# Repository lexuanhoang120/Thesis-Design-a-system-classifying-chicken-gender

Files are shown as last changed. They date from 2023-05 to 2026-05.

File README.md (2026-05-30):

# Chicken Gender Classification System

> **Undergraduate Thesis** — HCMC University of Technology (Bách Khoa), Mechatronics, 2022

A CNN-powered system that automatically sorts chickens by gender. Built from scratch: collected the dataset on a farm, trained the classifier, designed the mechanical singulation mechanism, wired the control electronics, and ran live experiments with real chickens.

---

## Highlights

- **95.9% classification accuracy** using a custom CNN with multi-frame majority voting — up from 91.5% single-frame
- **Self-collected dataset** — photographed hundreds of chickens one-by-one on a local farm, published on Kaggle
- **Full mechatronic system** — mechanical design (CAD), electrical wiring, embedded control (ATMega 2560), and computer vision — all integrated into a working prototype
- **~0.22s single-frame inference** for real-time use; **4.56s** with 20-frame voting for near-96% accuracy
- **4.4 pp accuracy gain** from a simple ensemble strategy that costs nothing but a few extra frames

---

## Results

**Experiment 1 — Single frame (200 chickens):**

| | Actual Cock | Actual Hen |
|---|---|---|
| **Predicted Cock** | **92** | 9 |
| **Predicted Hen** | 8 | **91** |

→ **91.5% accuracy**, ~0.22s per prediction

**Experiment 2 — Multi-frame voting (171 chickens):**

Take 20 frames, predict each independently, majority vote. Sum > 10 → hen, < 10 → cock.

| | Actual Cock | Actual Hen |
|---|---|---|
| **Predicted Cock** | **84** | 4 |
| **Predicted Hen** | 3 | **80** |

→ **95.9% accuracy** (+4.4 pp), ~4.56s per prediction  
→ Cock: 96.55%, Hen: 95.24%

The voting strategy trades speed for accuracy — worth it because the mechanical singulation is the bottleneck, not the classifier.

---

## How it works

```
Flock → Singulation mechanism → One chicken in the cage
                                       ↓
                              Camera captures image(s)
                                       ↓
                              CNN classifier → Cock or Hen
                                       ↓
                              Sorting gate → Correct bin
```

**Three integrated subsystems:**

| Subsystem | What it does | Key components |
|---|---|---|
| **Computer Vision** | Classifies gender from images | Custom CNN (4 conv + 2 dense), 256×256 RGB input |
| **Mechanical** | Isolates one chicken at a time | Gates, pusher plate, timing belt, stepper motor, servo |
| **Electrical & Control** | Orchestrates the sequence | ATMega 2560, IR sensors, motor drivers, 12V supply |

---

## The CNN classifier

### Data

Collected in person at a local chicken farm. Each bird was placed in a fixed cage under controlled LED lighting and photographed with a smartphone. The dataset was split into train/validation/test with augmentation.

<!-- 📦 [Kaggle Dataset](https://www.kaggle.com/datasets/hongxun/dataset-chicken-gender) · [Raw Data](https://www.kaggle.com/datasets/hongxun/raw-data-chicken-gender) · [Trained Model](https://www.kaggle.com/datasets/hongxun/classify-chicken-gender) · [All Materials](https://www.kaggle.com/datasets/hongxun/material-classify-chicken-gender) -->

### Architecture

| Layer | Details |
|---|---|
| Input | 256×256 RGB |
| Conv Block 1–4 | Increasing filters, ReLU, MaxPooling, Dropout |
| Dense | 2 fully-connected layers |
| Output | Sigmoid → binary (0 = Cock, 1 = Hen) |

Tested multiple architectures iteratively — selected the best balance of accuracy and inference speed.

### Key lessons

- **Environmental consistency matters.** Training images looked slightly different from on-site captures, which caused the real-world accuracy drop from training performance. Re-collecting data to match deployment conditions was the fix.
- **Chicken movement degrades single-frame accuracy.** A 20-frame voting strategy was a zero-cost fix — no model retraining, just capturing more frames and taking the majority.
- **Data collection is the hardest part.** Every sample means catching a chicken, placing it correctly, and labeling it. No shortcut for this.

---

## Demos & drawings

**Experiments:**

1. Building the model + initial testing — https://youtu.be/ve8OjjkXJxA
2. Results from experiment 1 — https://youtu.be/6x_dHk-QXaI
3. Results from experiment 2 + chicken measurements — https://youtu.be/hFi8iOCUlrs

**System animation:** https://youtu.be/mFdrJw7o6yE

**Design drawings:** [Algorithm](Drawing/algorithm.pdf) · [Mechanical](Drawing/mechanic.pdf) · [Electrical](Drawing/electric.pdf) · [Component selection](Drawing/selections.pdf)

---

## Project structure

```
.
├── VP ... HĐ11.pdf               # Full thesis (Vietnamese)
├── Drawing/                      # CAD drawings (DWG + PDF)
│   ├── algorithm.{dwg,pdf}
│   ├── mechanic.{dwg,pdf}
│   ├── electric.{dwg,pdf}
│   └── selections.{dwg,pdf}
├── #Kinematic diagram/           # Kinematic mechanism diagrams (Visio)
├── clip/                         # Experiment YouTube links
└── README.md
```

---

## Additional figures

### Classification problem

Classification problem

### Implementation planning

Implementation planning

### Build data

Build data

### Model structure

Model structure

Model structure 2

### Evaluation

Evaluation

### Experiment

Experiment

### Result

Result

### Improvement

Improvement

### Mechanical model

Mechanical model

Mechanical model 2

### Electrical model

Electrical model

Electrical model 2

### Summary

Summary

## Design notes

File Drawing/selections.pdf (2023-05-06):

## HỆ THỐNG PHÂN LOẠI GÀ

- Tách gà trong lồng thành từng con.
- Phân loại giới tính gà.

## PHẦN ĐIỆN

Động cơ

MỤC TIÊU

## PHẦN CƠ KHÍ

Cơ cấu tách gà

## Chọn động cơ RC Servo để phụ trách

hoạt động cho cụm đóng mở cửa lồng.

Cơ cấu đóng mở cửa

Thuỷ lực khí nén

RC Servo

- Khá phức
tạp. - Yêu cầu

thiết bị tạo
lưu chất. - Chi phí cao. - Hành trình

đáp ứng
chậm. - Cần khả năng

tạo xung
PWM của bộ
điều khiển
để điều
khiển động
cơ.

Bộ điều khiển

## Chọn kit Vi điều khiển làm bộ điều

khiển cho mô hình tách gà.

Programmable Logic
Controller (PLC)

Kit vi điều khiển

- Lập trình
đơn giản, dễ
sử dụng. - Được thiết

kế để sử
dụng trong
môi trường

# công nghiệp. - Giá thành rẻ. - Nhiều đầu

vào và đầu
ra.
- Giá thành
cao. - Không tận

dụng hết khả
năng của

# PLC. - Lập trình

phức tạp. - Cần thêm

thành phần
bảo vệ.

## PHẦN GIẢI THUẬT

## Chọn mô hình máy học CNN để đào tạo

phân loại giới tính gà.

Mô hình phân loại gà

Convolutional Neural Network (CNN)

Support Vector Machine
(SVM)
- Cho kết quả
chính xác
hơn.
- Sử dụng
trực tiếp ảnh
đầu vào để
đào tạo. | - Kiến trúc mô hình phức tạp hơn. - Thời gian
| dự đoán
lâu hơn. - Tốc độ suy

luận nhanh
hơn. - Kiến trúc mô

hình đơn

giản hơn. | - Kết quả chính xác không cao. - Bắt buộc
| phải chuyển dữ liệu thành vector.
Phương án | Ưu điểm | Nhược điểm

3 khối trụ xoay dọc

Lùa gà qua cửa hẹp

Sử dụng cụm băng tải

- Cơ cấu tách
gà thành
từng con
một. - Tầm hoạt
động rộng. | - Gia công chế tạo phức tạp. - Khả năng
| làm tổn thương

đối tượng. - Giá thành rẻ,

dễ gia công. - Số lượng gà

đi vào hệ
thống nhiều. - Tầm hoạt

động rộng.

- Cần cải
tiến để có
thể tách
gà. - Khả năng

làm tổn
thương đối
tượng cao. - Dễ gia công,

chế tạo. - Không làm

tổn thương

đối tượng. | - Tầm hoạt động hẹp. - Khó khăn
| trong việc đồng bộ hệ thống.

## Chọn phương án lùa gà qua khe hẹp

làm phương án tách gà.

- Hành trình
đáp ứng
nhanh. - Điều khiển

đơn giản.

Động cơ Servo

Động cơ thường

Động cơ bước

- Giá thành
cao. - Điều khiển

phức tạp. - Điều khiển

đơn giản. - Giá thành rẻ. - Phổ tốc độ

rộng. | - Bảo trì, bảo dưỡng thường xuyên. - Cần tích hợp

phanh. - Giá thành

cạnh tranh. - Có khả năng

giữ trục

động cơ. | - Khả năng trượt bước. - Ồn ào và
| sinh nhiệt cao.

## Chọn động cơ bước để dẫn động các

cụm trong mô hình tách gà.

YÊU CẦU

- Có khả năng tách gà thành từng con. - Ý tưởng đơn giản, dễ thiết kế.

YÊU CẦU

- Hoạt động ở hai trạng thái đóng và mở cửa. - Đơn giản và tiết kiệm.

YÊU CẦU

- Gọn nhẹ nhất có thể. - Có khả năng giữ trục khi không hoạt động. - Hoạt động êm ái.

YÊU CẦU

- Có khả năng nhận tín hiệu và xử lý để gửi tín hiệu tới các thành phần để điều khiển các cơ cấu thừa hành.

YÊU CẦU

- Khả năng nhận biết gà trống và gà mái.
- Đơn giản, dễ
sử dụng. - Giá thành rẻ.
- Có khả năng
giữ trục khi
không hoạt
động. - Hoạt động

êm ái.

Phương án | Ưu điểm | Nhược điểm | Phương án | Ưu điểm | Nhược điểm | Phương án | Ưu điểm | Nhược điểm | Phương án | Ưu điểm | Nhược điểm

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
1 | 2
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
1 | 2 | 3 | 4 | 5 | 6 | 7 | 8 | 9 | 10 | 11 | 12 | 13 | 14 | 15 | 16 | 17 | 18 | 19 | 20 | 21 | 22 | 23 | 24
3 | 4 | 5 | 6 | 7 | 8 | 9 | 10 | 11 | 12 | 13 | 14 | 15 | 16 | 17 | 18 | 19 | 20 | 21 | 22 | 23 | 24
Tờ: 1 | Số tờ: 4
Hướng dẫn | P. C. Bằng

Duyệt

PHÂN TÍCH VÀ THIẾT KẾ HỆ THỐNG PHÂN LOẠI GÀ

Chức năng | Họ và tên | Chữ kí | Ngày | LỰA CHỌN PHƯƠNG ÁN | Dấu | Khối lượng | Tỉ lệ
Thiết kế | L. X. Hoằng | | 21/05

Đại học Quốc gia TP.HCM
Trường Đại học Bách Khoa
Khoa Cơ khí
P. C. Bằng

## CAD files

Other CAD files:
Drawing/algorithm.dwg
Drawing/electric.dwg

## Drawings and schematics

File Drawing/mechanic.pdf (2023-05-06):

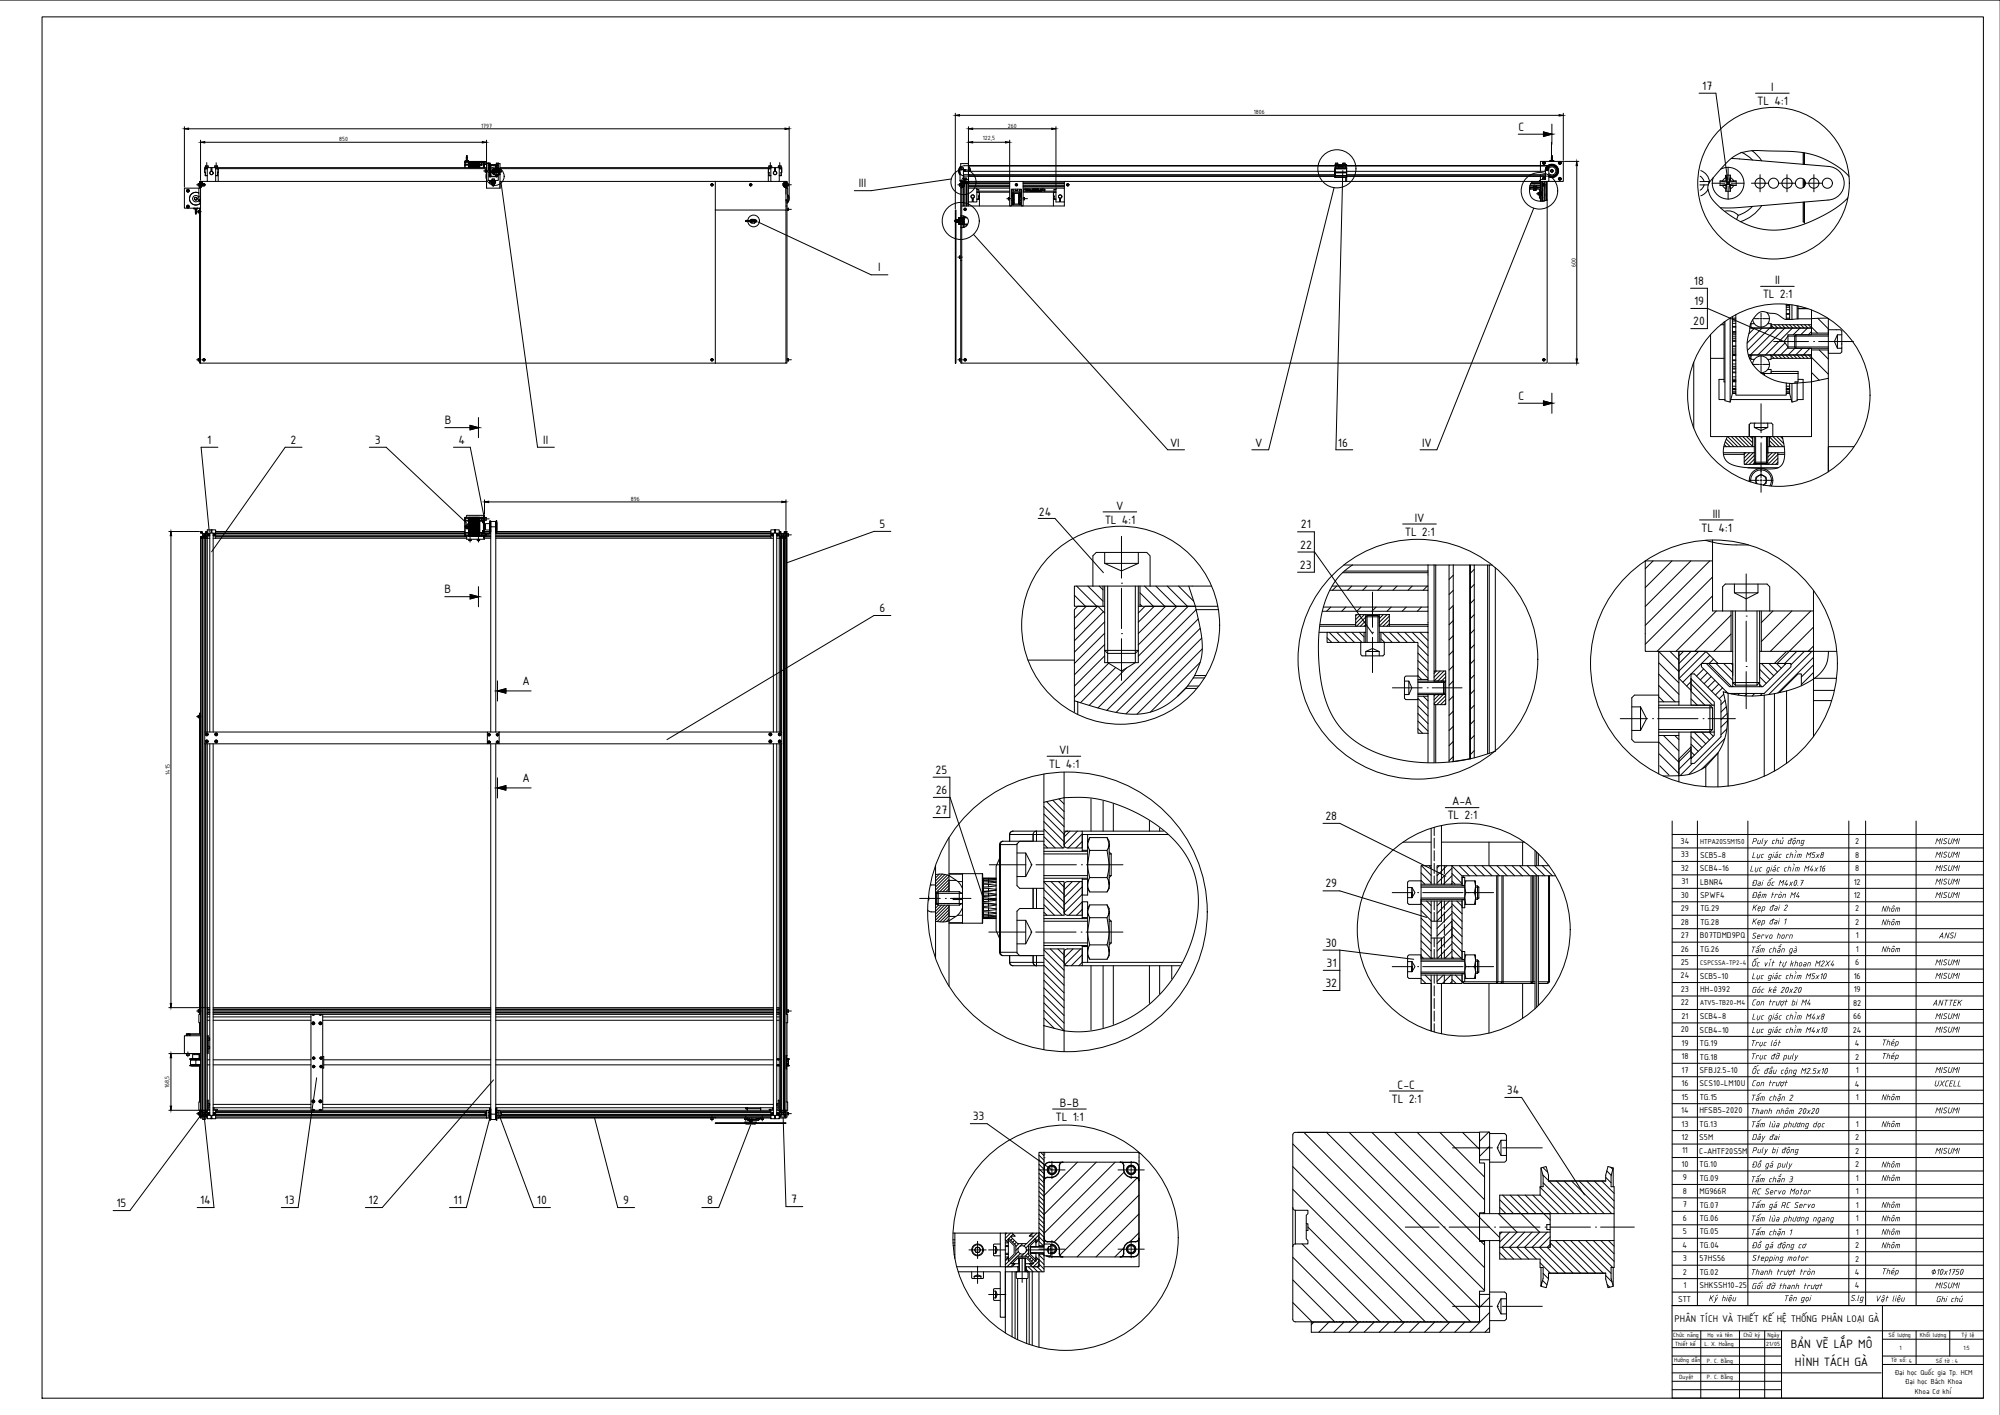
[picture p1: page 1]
L. X. Hoằng; Chức năng; Họ và tên; Chữ ký; Ngày; Thiết kế; Hướng dẫn; P. C. Bằng; Số lượng; Khối lượng; STT; Ký hiệu; Tên gọi; Vật liệu; Ghi chú; Tấm chặn 1; Tấm chắn 3; Tấm lùa phương dọc; Tấm chặn 2; Góc kê 20x20; Trục đỡ puly; Con trượt; Tấm chắn gà; RC Servo Motor; LBNR4 2

Puly chủ động
Lục giác chìm M5x8
Lục giác chìm M4x16
Đai ốc M4x0.7
Đệm tròn M4
Kẹp đai 2
Kẹp đai 1
Servo horn
Ốc vít tự khoan M2X4
Lục giác chìm M5x10

Con trượt bi M4
Lục giác chìm M4x8
Lục giác chìm M4x10
Trục lót
Ốc đầu cộng M2.5x10

Thanh nhôm 20x20
Dây đai
Puly bị động
Đồ gá puly

Tấm gá RC Servo
Tấm lùa phương ngang
Đồ gá động cơ
Stepping motor
Thanh trượt tròn
Gối đỡ thanh trượt

PHÂN TÍCH VÀ THIẾT KẾ HỆ THỐNG PHÂN LOẠI GÀ

BẢN VẼ LẮP MÔ
HÌNH TÁCH GÀ

Đại học Quốc gia Tp. HCM
Đại học Bách Khoa
Khoa Cơ khí

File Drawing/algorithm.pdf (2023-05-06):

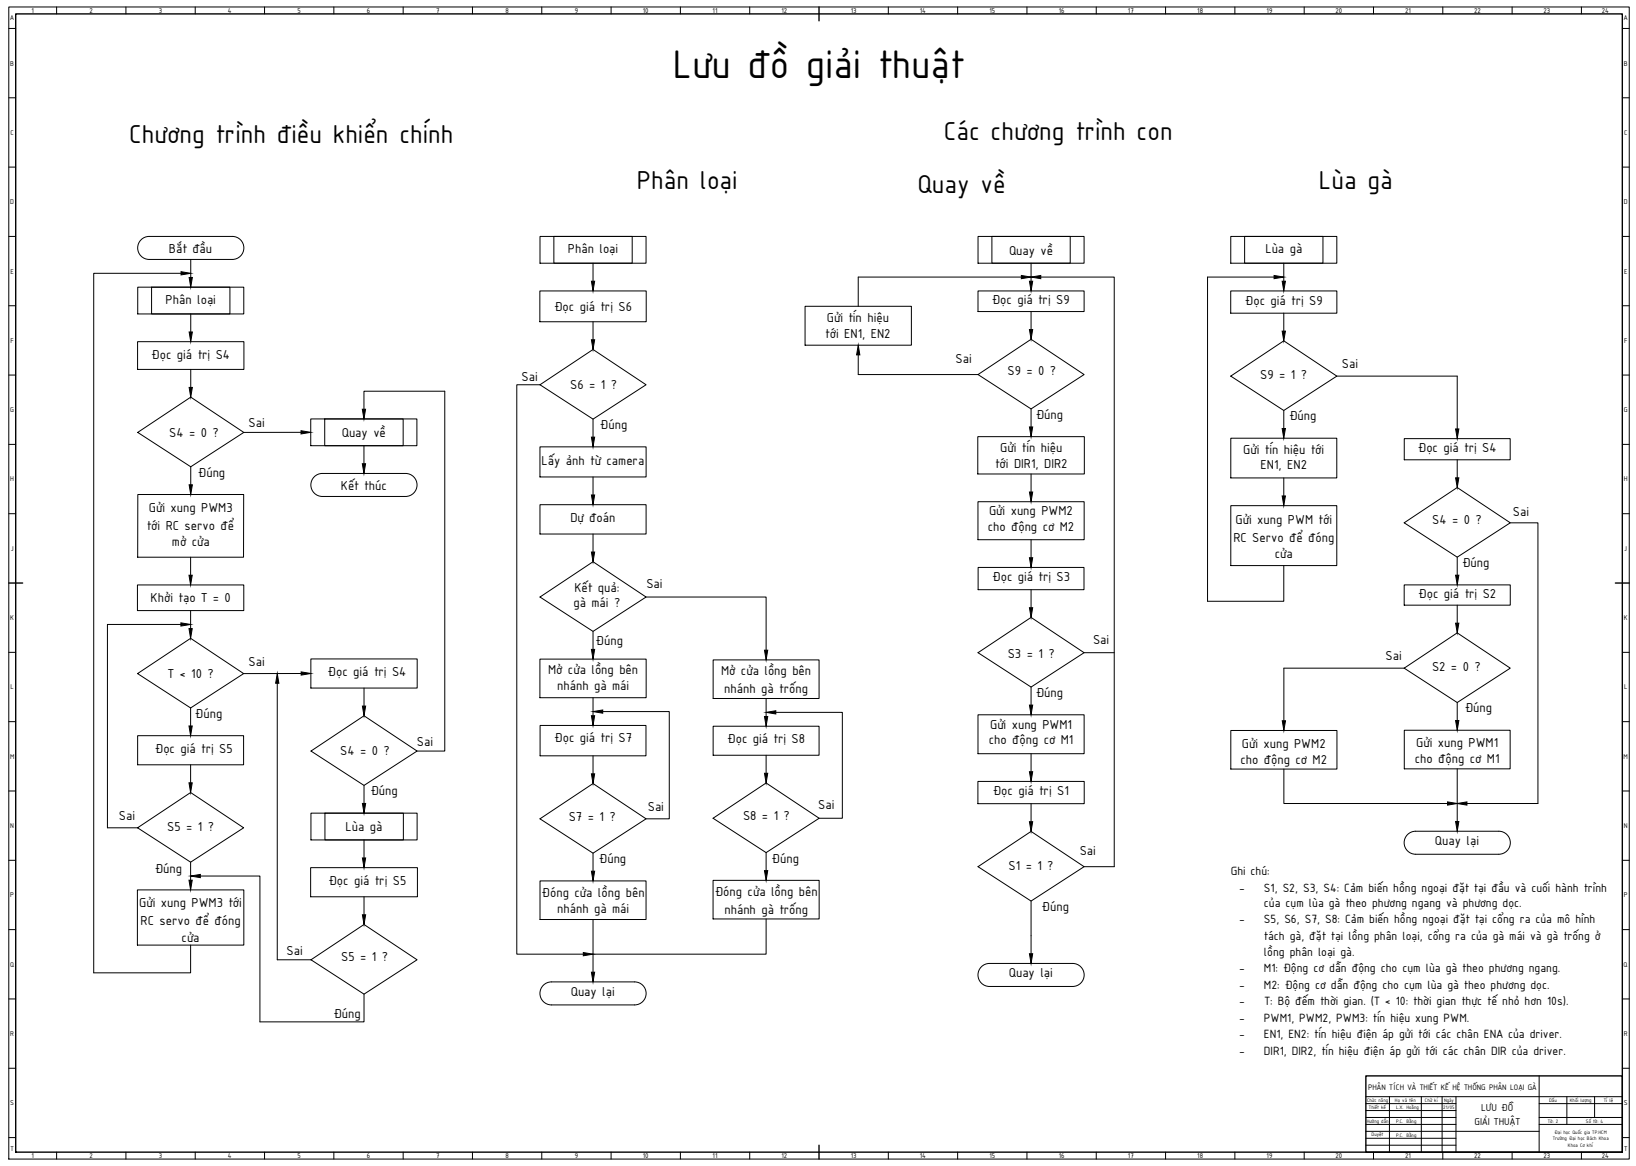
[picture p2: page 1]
Hướng dẫn; P.C. Bằng; Bắt đầu; Chương trình điều khiển chính; Các chương trình con; Lùa gà; Quay về; Dự đoán; Kết quả:; gà mái ?; Phân loại; Gửi xung PWM3; tới RC; servo để; mở cửa; Khởi tạo T = 0; Đọc; giá trị S5; Gửi xung; PWM2; cho động; PWM1; Gửi tín; hiệu; tới DIR1,; DIR2; Ghi chú: -; S1, S2, S3, S4: Cảm biến hồng ngoại đặt tại đầu và cuối hành trình; của cụm lùa gà theo phương ngang và phương dọc. -; S5, S6, S7, S8: Cảm biến hồng ngoại đặt tại cổng ra của mô hình; lồng phân loại gà. -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

Lưu đồ giải thuật

Đọc giá trị S9

Đọc giá trị S6

Gửi tín hiệu
tới EN1, EN2

Đọc giá trị S4

Quay về

Gửi tín hiệu tới

Lấy ảnh từ camera

Gửi xung PWM tới
RC Servo để đóng

Đọc giá trị S3

Đọc giá trị S2

Mở cửa lồng bên
nhánh gà mái

nhánh gà trống

Đọc giá trị S7

Đọc giá trị S8

Gửi xung PWM2
cho động cơ M2

Gửi xung PWM1
cho động cơ M1

Đọc giá trị S1

Đọc giá trị S5

Đóng cửa lồng bên

Gửi xung PWM3 tới
RC servo để đóng

tách gà, đặt tại lồng phân loại, cổng ra của gà mái và gà trống ở

PHÂN TÍCH VÀ THIẾT KẾ HỆ THỐNG PHÂN LOẠI GÀ

Chức năng | Họ và tên | Chữ kí | Ngày | LƯU ĐỒ GIẢI THUẬT | Dấu | Khối lượng | Tỉ lệ
Thiết kế | L.X. Hoằng | | 21/05

Đại học Quốc gia TP.HCM
Trường Đại học Bách Khoa

Khoa Cơ khí

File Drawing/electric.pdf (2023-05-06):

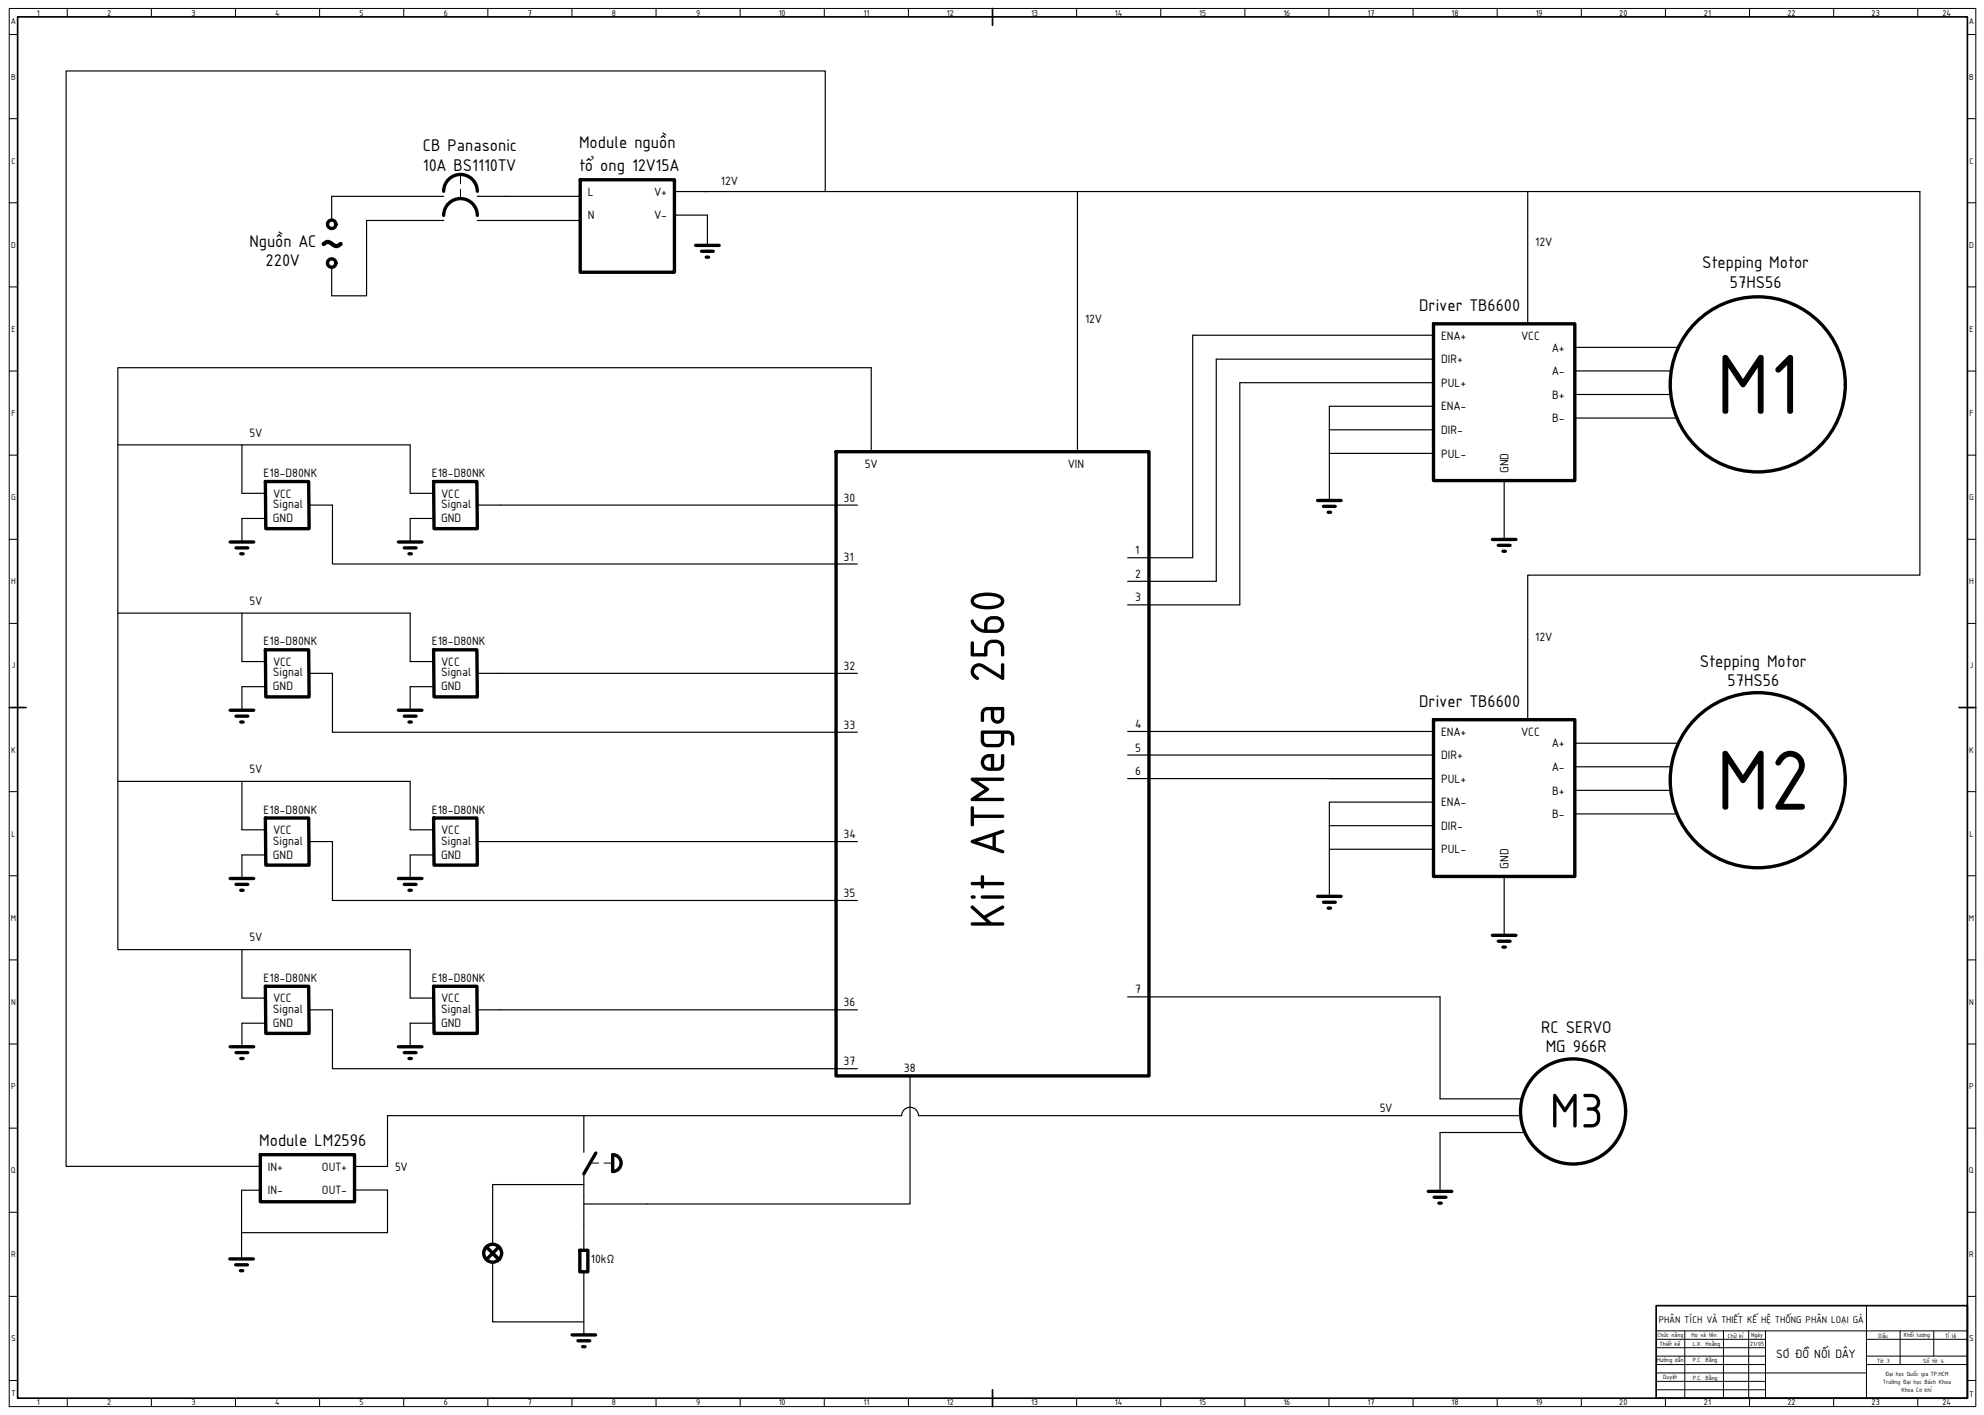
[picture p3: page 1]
BCADEFGHJKLMNPQRST; ABCDEFGHJKLMNPQRST 1; Số tờ: 4 Kit ATMega 2560; Hướng dẫn; P.C. Bằng; Module nguồn; tổ ong 12V15A; Nguồn AC; RC SERVO MG 966R; CB Panasonic 10A BS1110TV; Driver TB6600GND; Stepping Motor; PUL- 567; Module LM2596; ENA- 1; ENA- 4

Driver TB6600 12V | 12V

ENA+ VCC DIR+ PUL+ GND DIR-PUL- | A+ A-B+ B-

PHÂN TÍCH VÀ THIẾT KẾ HỆ THỐNG PHÂN LOẠI GÀ

Chức năng | Họ và tên | Chữ kí | Ngày | SƠ ĐỒ NỐI DÂY | Dấu | Khối lượng | Tỉ lệ
Thiết kế | L.X. Hoằng | | 21/05

Đại học Quốc gia TP.HCM
Trường Đại học Bách Khoa

Khoa Cơ khí
